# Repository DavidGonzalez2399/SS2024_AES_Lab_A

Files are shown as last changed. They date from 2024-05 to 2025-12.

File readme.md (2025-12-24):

# 🦾 IoT-Based Robotic Arm Sorting System

https://github.com/user-attachments/assets/bf0d83b5-6522-493c-a97c-d7caf1e9e134

## 📘 Project Overview

This repository contains the implementation of an **IoT-based automated sorting system** developed as part of the **Advanced Embedded Systems Lab** for the **Electronic Engineering program**.

The project was developed collaboratively by **Team A** and demonstrates how **distributed embedded systems** communicate wirelessly to control a **robotic arm and conveyor belt** for **color-based object sorting** in an industrial-like scenario.

---

## 🎓 Course Context

- **Course:** Advanced Embedded Systems Lab  
- **Program:** Electronic Engineering  
- **Term:** Summer Term 2024  
- **Project Type:** University Team Project  

---

## 👥 Team Members

- Andrew Antwan  
- **David Gonzalez**  
- Shahzaib Waseem  

---

## 🎯 Target Application

The goal of this project is to simulate an **automated industrial sorting system** for small colored cubes.

The cubes are transported on a conveyor belt. When a cube reaches a predefined position, it is detected by a distance sensor. A robotic arm then picks up the cube, analyzes its color using a color sensor, and decides whether to sort it into a container or return it to the conveyor belt.

This project helps students understand:
- Autonomous embedded systems
- Wireless sensor networks
- MQTT-based communication
- Industrial automation concepts

---

## 🧠 System Architecture

### Main Components

The system is composed of four distributed components:

- Conveyor Belt  
- Distance Sensor (Ultrasonic)  
- Robotic Arm  
- Color Sensor  

Each component runs on its own embedded controller and communicates wirelessly using **MQTT over Wi-Fi**.

---

## 🔌 Hardware & Technologies

### Microcontrollers & Devices

| Device | Responsibility |
|---|---|
| Arduino Uno WiFi Rev2 | Distance sensor & conveyor belt control |
| Raspberry Pi Pico W | Robotic arm motors & color sensor |
| Raspberry Pi 4 | MQTT broker (central hub) |

### Communication

- **Protocol:** MQTT  
- **Broker:** Mosquitto (running on Raspberry Pi 4)  
- **Architecture:** Publish / Subscribe  

---

## 📡 MQTT Communication Model

### Publishers
- Distance Sensor → publishes object detection events  
- Color Sensor → publishes detected color  

### Subscribers
- Conveyor Belt → subscribes to stop/start commands  
- Robotic Arm → subscribes to detection and color messages  

The **robotic arm acts as both a subscriber and a publisher**, making it the central decision-making unit in the system.

---

## 🔄 System Control Flow (One Full Cycle)

The system operates in a continuous loop. One complete cycle is described below:

1. Conveyor belt runs continuously  
2. Distance sensor detects an object  
3. Distance sensor publishes a stop message  
4. Conveyor belt stops  
5. Robotic arm picks up the object  
6. Robotic arm moves the object to the color sensor  
7. Color sensor measures RGB values  
8. Detected color is published via MQTT  
9. Robotic arm decides:
   - If the object is **blue**, it is placed into the sorting container  
   - If the object is **not blue**, it is returned to the conveyor belt  
10. Robotic arm returns to its neutral position  
11. Conveyor belt resumes movement  
12. The cycle repeats  

---

## 🧩 Software Design Overview

### Distance Sensor Module
- Based on the HC-SR04 ultrasonic sensor  
- Detects objects within a configurable distance threshold  
- Publishes detection events via MQTT  

### Color Sensor Module
- Measures RGB values using frequency-based output  
- Determines dominant color via comparison logic  
- Publishes color result via MQTT  

### Motor Control Module
- Converts angles into PWM duty cycles  
- Controls robotic arm positions:
  - Pickup position  
  - Hover above color sensor  
  - Drop position  
  - Reset position  

### Conveyor Belt Module
- Controls stepper motor movement  
- Starts and stops based on MQTT messages  
- Uses direction and step pins for control  

---

## 🧪 Use Cases

### ✅ Blue Object Sorting
- Object is detected  
- Robotic arm picks it up  
- Color sensor detects blue  
- Object is placed into the sorting container  

### 🔁 Non-Blue Object Handling
- Object is detected  
- Robotic arm picks it up  
- Color sensor detects non-blue  
- Object is returned to the conveyor belt  

---

## 🛠️ System Setup & Usage

1. Place a container for blue objects at approximately 60–80° counterclockwise from the robotic arm  
2. Activate a suitable WLAN  
3. Configure SSID and password on all devices  
4. Connect the Raspberry Pi 4 (MQTT broker) to the WLAN  
5. Set the broker IP address on all sensor and actuator nodes  
6. Power all system components  
7. Place a cube on the conveyor belt  
8. Observe automatic detection, classification, and sorting  
9. The system continues operating autonomously  

---

## 📊 Diagrams (Placeholders)

Add the following diagrams to the repository for clarity:

- **Figure 1:** Sequence Diagram  
- **Figure 2:** Block Diagram  
- **Figure 3:** MQTT Communication Layout  
- **Figure 4:** Class Diagram  

---

## 📁 Project Management

- **Version Control:** GitHub  
- **Collaboration Method:**  
  - Weekly virtual planning meetings  
  - In-person hardware integration sessions  
- **Task Assignment:** Volunteer-based and skill-oriented  

---

## 📚 References

- Arduino WiFiNINA Library  
- ArduinoMqttClient Library  
- Mosquitto MQTT Broker  
- Raspberry Pi Pico W (MicroPython)  

---

## ✅ Learning Outcomes

This project demonstrates:
- Distributed embedded system design  
- MQTT-based IoT communication  
- Wireless sensor networks  
- Event-driven control logic  
- Hardware–software co-design  

---

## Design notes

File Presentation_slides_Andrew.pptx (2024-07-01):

## Color Sensor

- makeConnection
- Publish
- Pins
- measureRed
- measureGreen
- measureBlue
- Decide_color

https://www.mouser.com/catalog/specsheets/tcs3200-e11.pdf

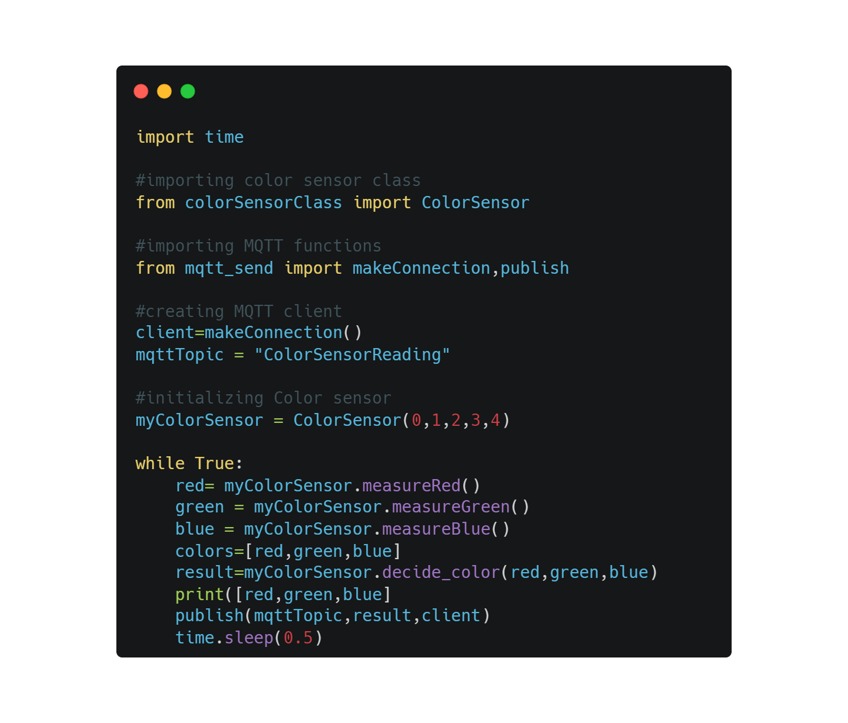
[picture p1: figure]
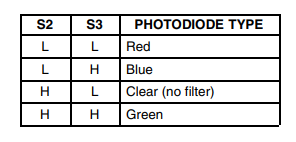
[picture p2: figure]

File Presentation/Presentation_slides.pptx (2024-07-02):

## Robotic Arm

Using MQTT

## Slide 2

Daivd

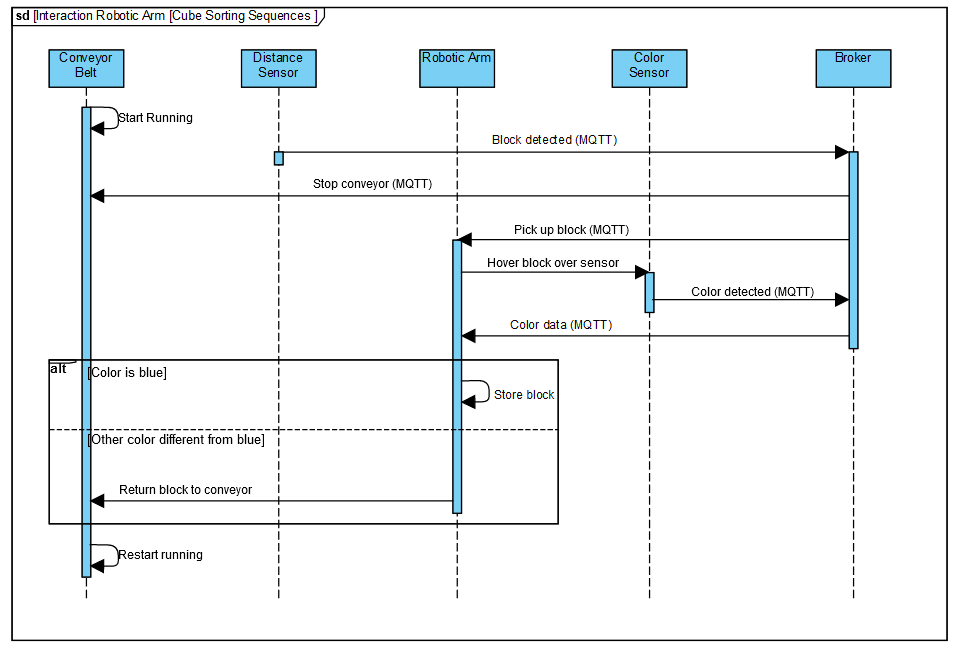
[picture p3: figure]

## Color Sensor

- makeConnection
- Publish
- Pins
- measureRed
- measureGreen
- measureBlue
- Decide_color

Andrew


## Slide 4

Importing libraries for MQTT, BLYNK, time and motor usage

-Declaring global for color sensor readings and message from conveyor belt
-Callbacks from for color sensor and conveyor belt topic and message

-Making connection to the MQTT
-Defining motors angles and speed
-Subscribing to conveyor belt

loop

-When conveyor belt sends a message, the robotic arm goes to conveyor belt and picks the cube
- The robotic arm place the cube on top of the color sensor

When the cube is blue, the robotic arm sorts it in the box, otherwise it goes to the conveyor belt again

David

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
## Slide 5

-Importing libraries for MQTT and WLAN
-Defining the pins for the motor driver, WLAN and MQTT status

-Connecting to WiFi and MQTT broker
-Subscribing to BoxDetection

loop

-if the MQTT is not connected yet, LED for MQTT status is low and the conveyor belt is static

-When no message from the ultrasonic is received, the conveyor belt moves, otherwise it will remain stop until the ultrasonic allows it

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
## Class diagrams

Shahzaib

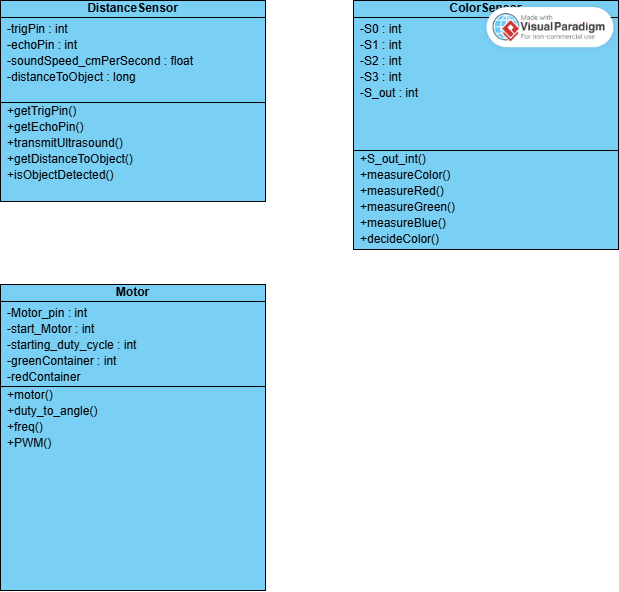
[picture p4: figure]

Conveyer belt

-dirPin : int
-stepPin : int

+move : void
+stop : void

## Conveyor belt motor

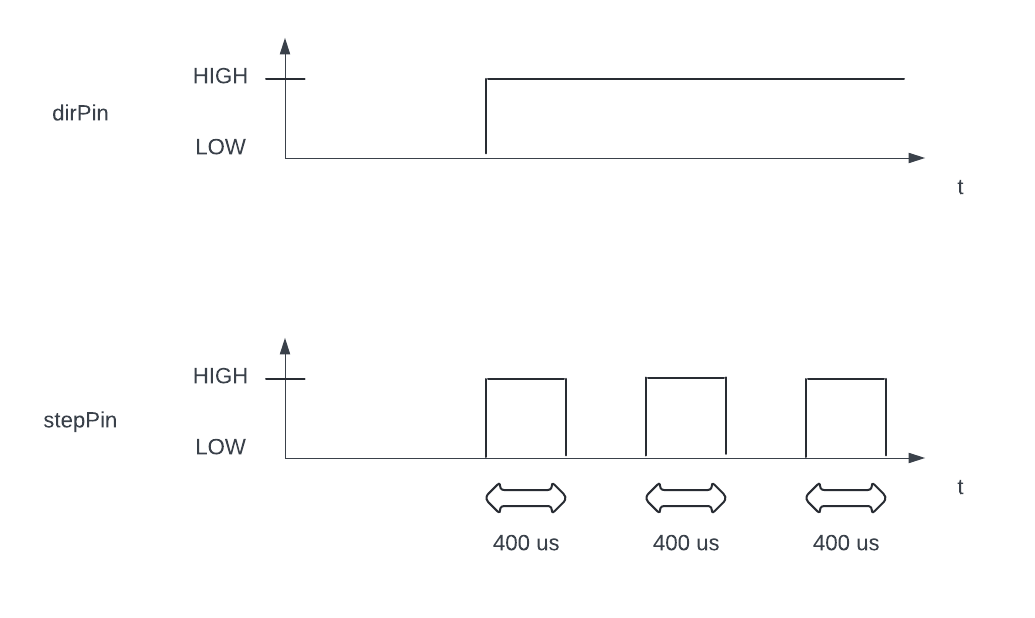
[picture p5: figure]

## Distance sensor (HC-SR04)

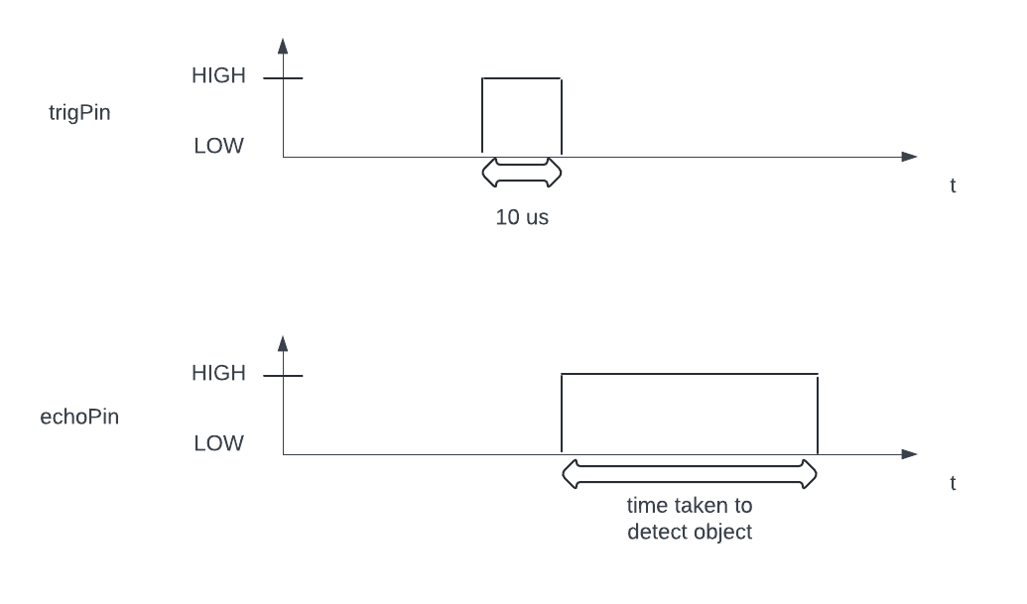
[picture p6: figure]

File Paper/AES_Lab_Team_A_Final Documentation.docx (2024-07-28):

Documentation

Team A

28.05.2024

Important Notes:

- The descriptions in italics in this document (except for some section headings) are exemplary and explanatory and must be removed from the completed report.
- Identify which section of this report was created by which team member
- Your documentation should have ca. 8 pages.

# 1 Team members

Andrew Antwan

David Gonzalez

Shahzaib Waseem

# 2 Introduction

## 2.1 Internet of Things

The internet of things (IoT) consist to connect everyday objects to the internet, which can collect and share the data by utilizing the environment in which they are working. Our project implements devices such as Arduino and Raspberry Pi to control a conveyor belt and robotic arm. These devices talk to each other through the internet to make the system work autonomously.

## 2.2 Wireless Sensor Networks

Wireless sensor networks are collections of small sensors that can sense and transmit data wirelessly, such as temperature or object detection. The color sensor and ultrasonic sensor are a part of this network in our project. They transmit data wirelessly (via an Arduino and a Raspberry Pi) to the main controllers. This facilitates wireless monitoring and control of the robotic arm and conveyor belt.

## 2.3 What is the target application of your project?

Our research aims to implement an automated system for sorting small colored cubes in an industrial environment. The cubes are moved by the conveyor belt; when a cube is detected by the ultrasonic sensor, the robotic arm sorts the cube according to its color. This system can help students to understand how industries sort items quickly and efficiently without needing human intervention.

# 3 Concept description


Figure 1 Sequence diagram

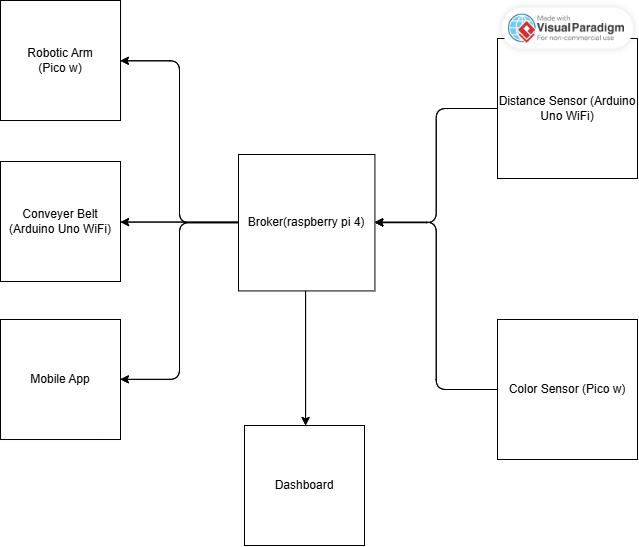
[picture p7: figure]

Figure 2 Block Diagram

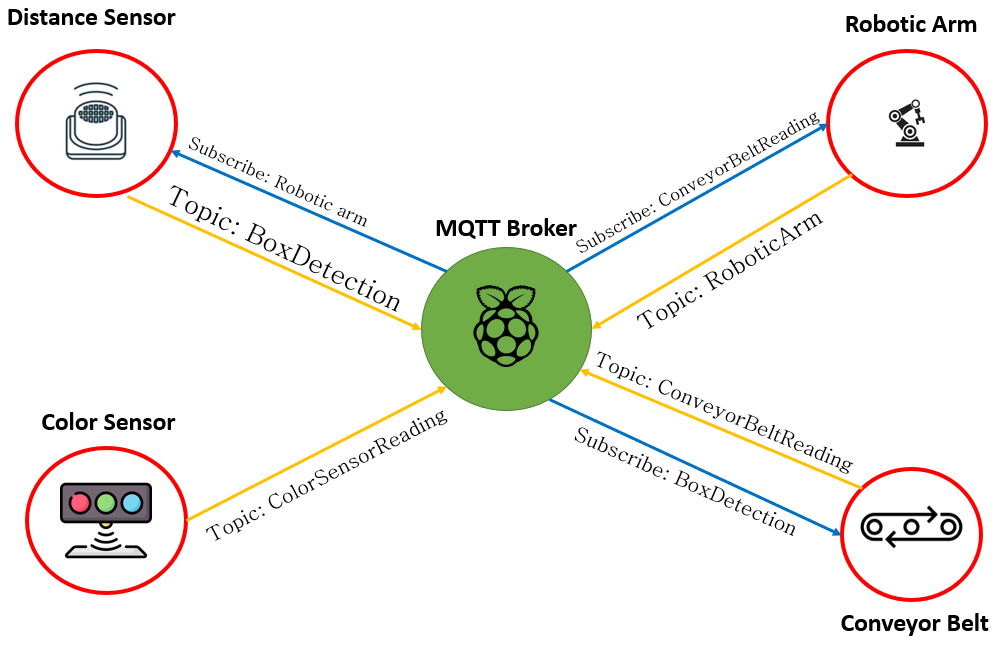
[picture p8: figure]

Figure 3 MQTT Communication layout

The project is mainly consisting of 4 components, namely a Color sensor, Robotic Arm, distance sensor and a conveyer belt. The operation starts by the conveyer belt where it runs until the distance sensor detects that a block has reached a specific region. The distance sensor sends a signal to both the conveyer belt in order to stop and to the robotic arm to pick up the block. The robotic arm picks up the block and hovers it over the color sensor where it sends the color detected to the robotic arm where it decides if the color is to be stored in a separate box or returned to the conveyer belt one more time.

# 4 Project/Team management

## 4.1 Project Methods

We used mainly GitHub as a common repository for file sharing and to sync up all our work. This allowed us to modify each others work if needed without worrying about overwriting the previous work.

## 4.2 Breakdown

For organizing the work we mainly met 2 times a week. One during the weekends -mainly virtually – to organize tasks and divvy up the work amongst ourselves. This was followed by another meeting in person every Tuesday where we show up the progress on the real hardware and where we would brainstorm ideas if anyone is having problems with their tasks.

We didn’t have a rigid hierarchy in the project, the assignment of tasks is mainly done on a volunteer basis depending on the ability and the vision of each.

## 4.3 Division of tasks

Andrew | David | Shahzaib
Color sensor code | Robotic arm code | Distance sensor code
Python MQTT library | Conveyer belt code | Conveyer belt code
Color sensor base 3d design | Robotic Arm 3d design | Arduino MQTT library
Class diagram | Distance sensor 3d design
| Sequence diagram

# 5 Technologies

## Arduino Uno Wifi Rev2

The Arduino Uno Wifi Rev2 is used as a constrained device to control both the distance sensor and the conveyer belt. It offers 48 KB of flash memory with 6.144 KB of SRAM, making it a C0 constrained device. It uses the WiFiNINA library to use the Wi-Fi functionality and the ArduinoMqttClient in order to use mqtt functionality.

## Raspberry Pi Pico W

The raspberry pi pico w is used to control the color sensor and the robotic arm motors. Both of them communicate over wifi with MQTT protocol using the umqtt simple.py library. It offers stronger specs than the pre-mentioned Arduino uno wifi with 264KB of SRAM and 2MB of flash memory which offers more flexibility which is handy specially that it uses Python which compared to C++ used in Arduino programming can require larger storage space.

## Raspberry PI 4

The raspberry pi 4 operates as the central hub that hosts the MQTT broker, sending and receiving all the information from the external nodes

## Mosquitto

The nodes all communicate together using the MQTT protocol where nodes as distance sensor and color sensor are publishers of information and nodes as conveyer belt and robotic arm are subscribers. Keeping in mind that some nodes as the robotic arm is both a subscriber and a receiver at the same time. To use the mqtt protocol we are using the Mosquitto client on the raspberry pi 4 which offers easy setup and reliable performance.

# 6 Implementation

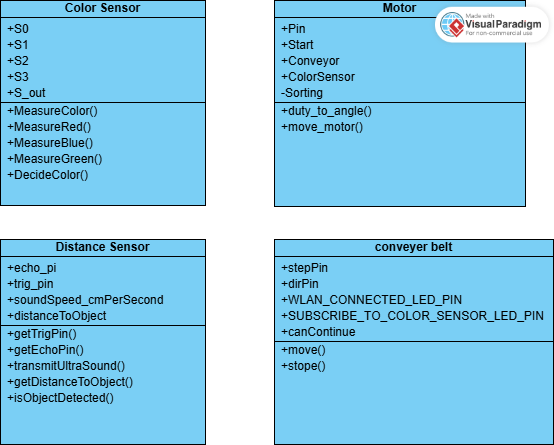
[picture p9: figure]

Figure 3 Class diagram

## Color Sensor

The color sensor has 4 inputs in order they are S0,S1,S2,S3 and one output that gives a frequency inversely relating to the intensity of the color measured. These can be split into two groups: frequency amplification and filter. The pins S0 and S1 are responsible for amplification the measured frequency. In our code these values are set to 1 and 0 respectively to give us a scaling value of 20%. The filter pins S2 and S3 are changed depending on the required color to be measured according to the figure below.

Figure 4 S2 and S3 assignment

These pins are changed using the methods MeasureRed, MeasureGreen and MeasureBlue.

The values received from each function are being compared by the DecideColor function and sees the lowest in the RGB values receives and sets this as the “result” of the measurements.

## Motor

The motor class starts by defining the input pin where the motor is connected and some constants for the various positions the motor will be in. these are the values of the degrees each motor needs to be set to in order to catch the cube from the conveyer belt, hover over the color sensor, store it in the box and return to the start position one more time.

Since the motors need an input of different PWM duty cycles instead of degrees, the function duty_to_angle that transforms the duty cycle to the needed angle. This is then fed into the move_motor function to move to the desired position.

6.3 Distance sensor

The distance sensor class is based on the HCSR-04 proximity or distance sensor and contains two private attributes: the trigger pin and the echo pin. These two attributes are needed in the constructor of the class to instantiate an object of this class. The class uses methods like transmitUltrasound, and getDistanceToObject which although are available for the user to access and use, are mainly components of the isObjectDetected method. This method takes in an argument for an amount of distance in centimeters which serves as a threshold to return true or false when an object is detected within this distance threshold.

6.3 Conveyor belt

The conveyor belt class have three attributes: dirPin, stepPin, and canContinue. The two pins are used in the move and stop methods. Setting dirPin to 1, and generating a 50% duty cycle PWM on the stepPin with a frequency of 1250 Hz or period of 800 microseconds will move the conveyor belt, and setting both these pins to 0 indefinitely will stop the conveyor belt. Upon receiving a message from the distance sensor, depending on the contents of said message, the canContinue property can set to 0 or 1.

# 7 Use Case

The functionality of the system makes it so that there are two possible use cases:

- To let a blue box be sorted out
- To let a non-blue box continue its journey on the conveyor belt

To use our system, the following steps must be taken:

1. Place a container for sorted blue boxes at about 60 to 80 degrees counterclockwise from the robotic arm
2. Activate or turn on a suitable WLAN
3. Ensure that the SSID and password of the WLAN are correctly set up in all the WSNs
4. Connect the Raspberry Pi Broker to the WLAN
5. After the Raspberry Pi Broker connects to the WLAN, ensure that its IP address is correctly set up in all WSNs
6. Provide power to each of the WSNs (robotic arm, color sensor, distance sensor, conveyor belt), and ensure they all connect to the same WLAN and establish an MQTT connection with the Raspberry Pi Broker on its dedicated IP address
7. Place a blue or non-blue box on the conveyor belt, depending on the use case chosen
8. With the conveyor belt powered on, allow the box to travel forward on the conveyor belt
9. Wait for the selected box to get detected by the distance sensor, which would cause the conveyor belt to stop moving
10. Wait for the robotic arm to pick up the box from the conveyor belt at the box’s stopping position
11. Wait for the robotic arm to carry this picked up box towards the color sensor, and allow its color to be determined
12. Depending on the use case chosen, wait for a non-blue box to be placed back on the conveyor belt and have it continue its movement, or wait for a blue box to be dropped off into a container
13. Allow the robotic arm to return to its neutral/starting position. Then repeat from step 7

# 8 Sources/References

Provide the sources on the technologies and algorithms you used in your project (Github).

Advanced Embedded Systems Lab Summer term 2024

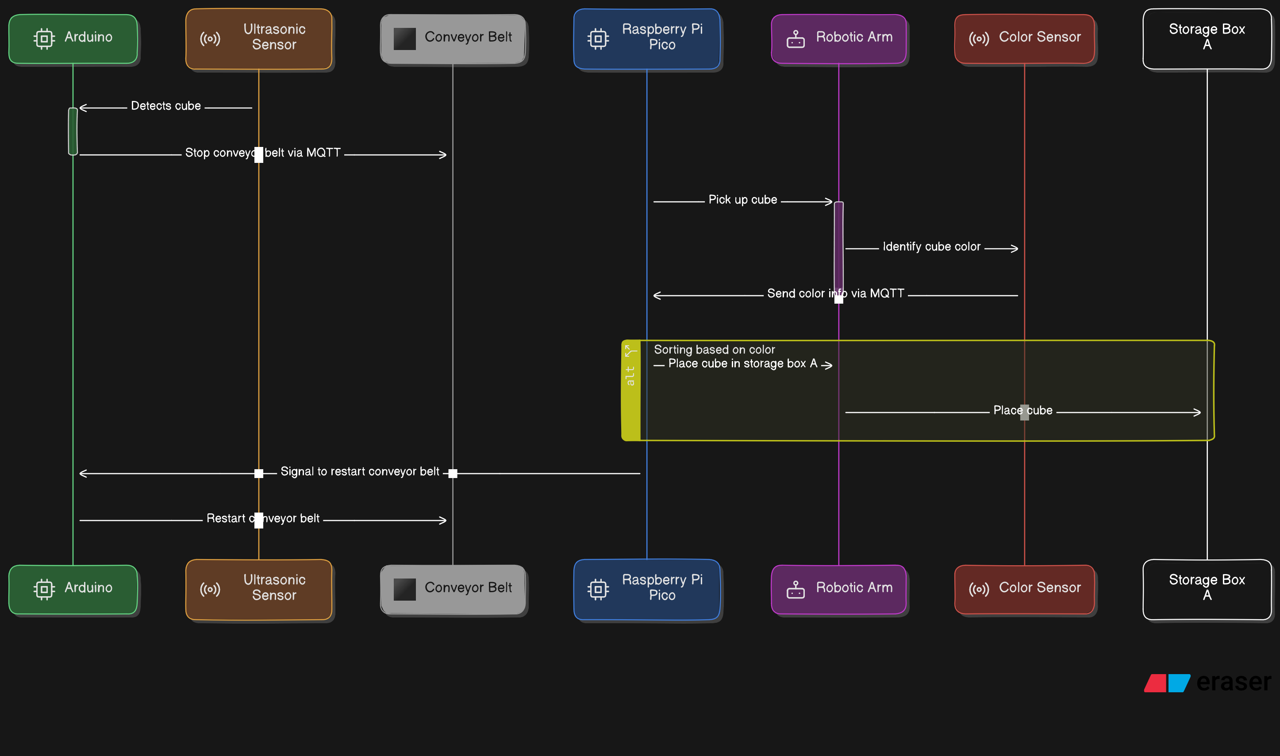
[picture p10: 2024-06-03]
Diagrams/diagram-export-6-3-2024-5_08_39-PM.png

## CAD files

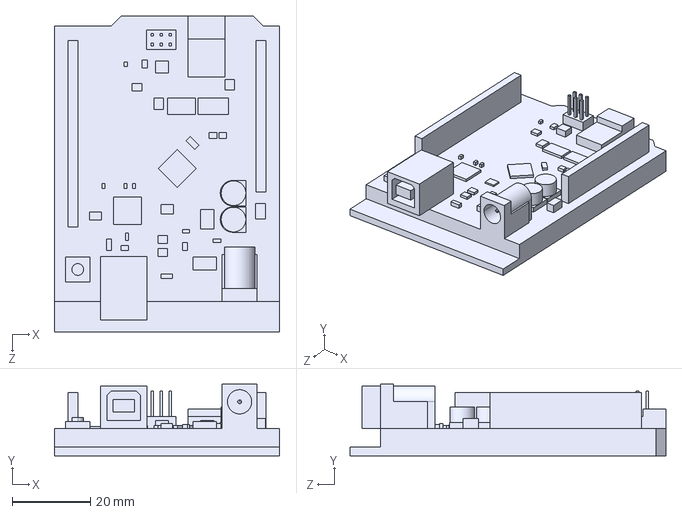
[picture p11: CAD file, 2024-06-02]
Design/arduino-UNO.STEP
57.5 x 18.3 x 80.7 mm

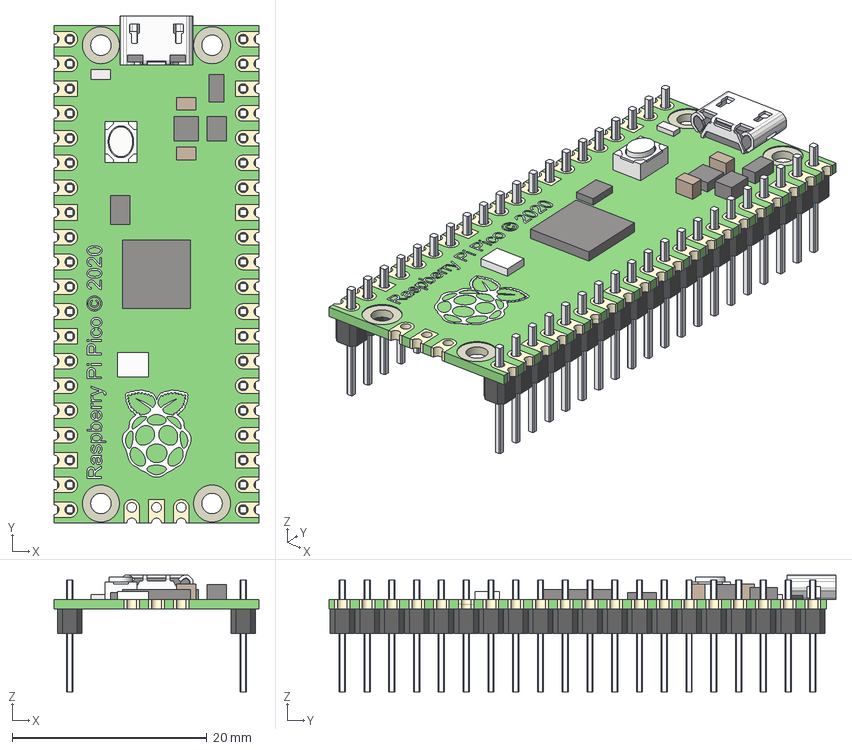
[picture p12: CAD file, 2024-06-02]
Design/raspberry pi pico with contacts.step
21.0 x 52.0 x 12.0 mm
ножка x 20
ножка v3(Mirror) x 20

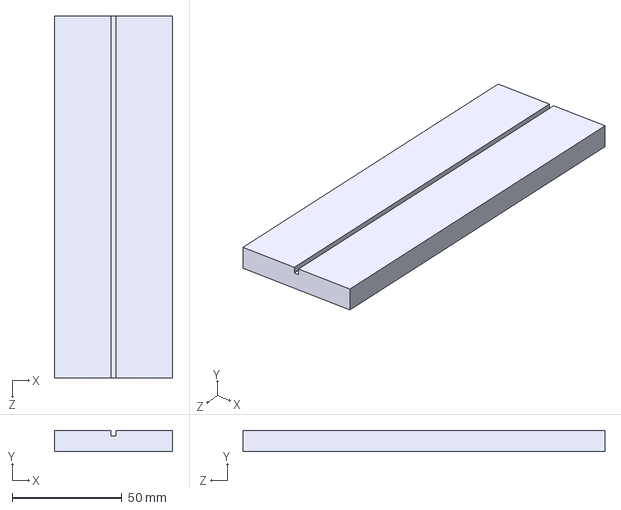
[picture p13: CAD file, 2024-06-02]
Design/breadboard.STEP
54.0 x 9.60 x 165.0 mm

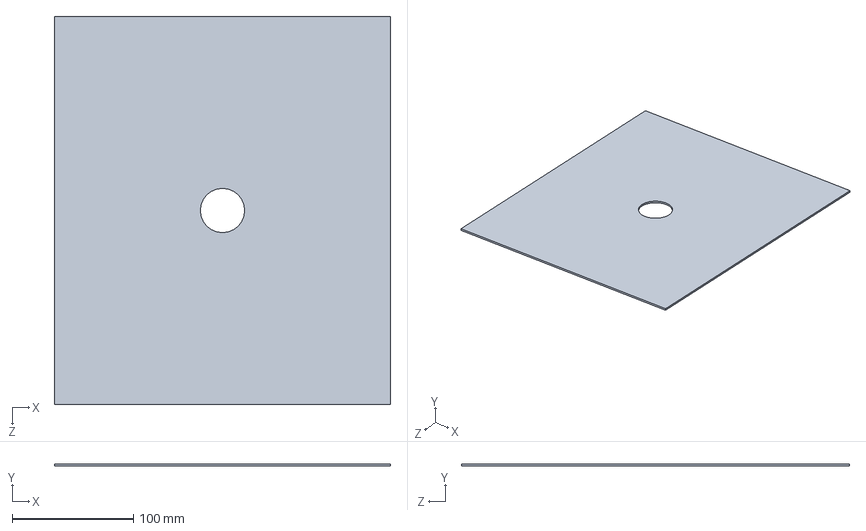
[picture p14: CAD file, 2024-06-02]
Design/Top.SLDPRT
277.3 x 2.00 x 320.0 mm

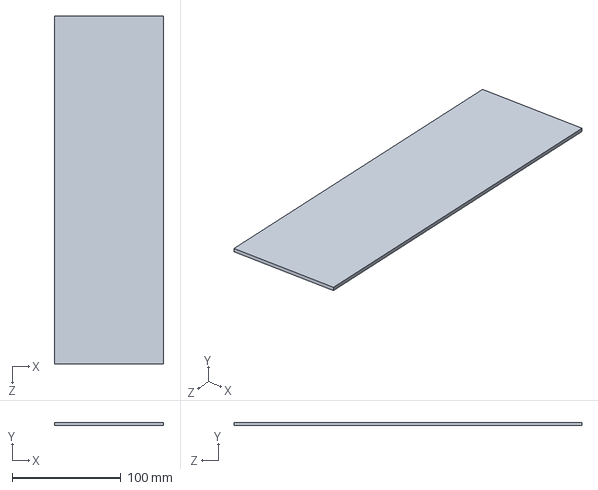
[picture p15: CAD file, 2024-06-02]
Design/Sides.SLDPRT
100.0 x 3.00 x 320.0 mm

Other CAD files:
Design/base.SLDPRT

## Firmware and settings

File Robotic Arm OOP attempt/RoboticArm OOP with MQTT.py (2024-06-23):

from motor_class import Motor, most_common
from mqtt_receive import makeConnection,subscribe
from mqtt_send import publish
import time

readings=[]
conveyerBelt_message=0

def colorSensor_callback(topic, response):
    global readings
    readings.append(response)
    return response
def conveyerbelt_callback(topic,response):
    global conveyerBelt_message
    
    if response==b'1':
        conveyerBelt_message=1
    print(f'response is {response} flag is {conveyerBelt_message}')

client = makeConnection()

motor1_wait_ms=20
motor2_wait_ms=50
motor3_wait_ms=20
motor5_wait_ms=10
motor6_wait_ms=1 

motor_wait_list=[motor1_wait_ms,motor2_wait_ms,motor3_wait_ms,motor5_wait_ms,motor6_wait_ms]
motor1 = Motor(15,101,101,101,0,180,101,0)
motor2 = Motor(8,40,12,12,35,30,15,35)
motor3 = Motor(7,150,164,140,183,150,164,150)
motor5 = Motor(5,155,110,120,106,110,105,110)
motor6 = Motor(6,180,60,60,60,180,180,60)

motor_list=[motor1,motor2,motor3,motor5,motor6]
client.set_callback(conveyerbelt_callback)
subscribe('ConveyorBeltReading', client)
while 1:
    
    client.check_msg()
    while conveyerBelt_message==1:
        for i in range(len(motor_list)):
            motor_list[i].move_motor(motor_list[i].start,motor_list[i].conveyor,motor_wait_list[i])
        #motor3.move_motor(motor3.conveyor,motor3.conveyor_adjustment,motor3_wait_ms)
        #motor3.conveyor=motor3.conveyor_adjustment
        for i in range(len(motor_list)):
            motor_list[i].move_motor(motor_list[i].conveyor,motor_list[i].conveyor_adjustment,motor_wait_list[i])

        for i in range(len(motor_list)):
            motor_list[i].move_motor(motor_list[i].conveyor_adjustment,motor_list[i].color,motor_wait_list[i])

        client.set_callback(colorSensor_callback)
        subscribe('ColorSensorReading', client)
        start=time.ticks_ms()
        end=time.ticks_ms()
        while end-start<5000:
           time.sleep(0.5)
           client.check_msg()
           end=time.ticks_ms()
        result = most_common(readings)
        print(result)
        if result == b'blue':
            for i in range(len(motor_list)):
                motor_list[i].move_motor(motor_list[i].color,motor_list[i].storing,motor_wait_list[i])
            for i in range(len(motor_list)):    
                motor_list[i].move_motor(motor_list[i].storing,motor_list[i].start,motor_wait_list[i])
        else:
            for i in range(len(motor_list)):
                motor_list[i].move_motor(motor_list[i].color,motor_list[i].returnbox_adjustment,motor_wait_list[i])
            for i in range(len(motor_list)):
                motor_list[i].move_motor(motor_list[i].returnbox_adjustment,motor_list[i].returnbox,motor_wait_list[i])
            for i in range(len(motor_list)):
                motor_list[i].move_motor(motor_list[i].returnbox,motor_list[i].start,motor_wait_list[i])
        readings=[]
        publish('RoboticArm','1',client)
        client.set_callback(conveyerbelt_callback)
        subscribe('ConveyorBeltReading', client)
        conveyerBelt_message=0

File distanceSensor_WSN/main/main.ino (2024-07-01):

#include "DistanceSensor.h"
#include "WLAN.h"
#include "MQTT.h"

#define TRIG_PIN 12
#define ECHO_PIN 11
#define WLAN_CONNECTED_LED_PIN 7
#define PUBLISH_TO_CONVEYER_BELT_LED_PIN 6
#define SUBSCRIBE_TO_COLOR_SENSOR_LED_PIN 5
#define NEAR_THRESHOLD_CMS 18

DistanceSensor distanceSensor(TRIG_PIN, ECHO_PIN);

void setup() {
  
  Serial.begin(9600);
  while (!Serial) {
    ; // wait for serial port to connect. Needed for native USB port only
  }
  pinMode(LED_BUILTIN, OUTPUT);
  pinMode(WLAN_CONNECTED_LED_PIN, OUTPUT);
  pinMode(PUBLISH_TO_CONVEYER_BELT_LED_PIN, OUTPUT);
  pinMode(SUBSCRIBE_TO_COLOR_SENSOR_LED_PIN, OUTPUT);
  
  connectToWifi();

  connectToMQTTBroker();

  digitalWrite(LED_BUILTIN, HIGH);

  subscribeToTopic("RoboticArm");

}


void loop() {

  if(!mqttClient.connected()){

    digitalWrite(LED_BUILTIN, LOW);

    connectToWifi();

    connectToMQTTBroker();

  } else {

    digitalWrite(LED_BUILTIN, HIGH);
  
    if(distanceSensor.isObjectDetected(NEAR_THRESHOLD_CMS)){

      publishMessage("1", "BoxDetection");
      
    }

    mqttClient.poll();

  }

  delay(100); 

}

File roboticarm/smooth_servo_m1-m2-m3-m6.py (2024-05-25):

import machine
import time

# Define pin numbers for each motor
MOTOR1_PIN = 15
MOTOR2_PIN = 8
MOTOR3_PIN = 7
MOTOR4_PIN = 6

START_motor1 = 50
START_motor2 = 40
START_motor3 = 120
START_motor4 = 180

RED_CONTAINER_motor1 = 135
RED_CONTAINER_motor2 = 30


GREEN_CONTAINER_motor1 = 160
GREEN_CONTAINER_motor2 = 10
GREEN_CONTAINER_motor3 = 140
GREEN_CONTAINER_motor4 = 70


# Initialize PWM objects for each motor
MOTOR1 = machine.PWM(machine.Pin(MOTOR1_PIN))
MOTOR2 = machine.PWM(machine.Pin(MOTOR2_PIN))
MOTOR3 = machine.PWM(machine.Pin(MOTOR3_PIN))
MOTOR4 = machine.PWM(machine.Pin(MOTOR4_PIN))

MOTOR1.freq(50)  # Set PWM frequency for all motors
MOTOR2.freq(50)  # Set PWM frequency for all motors
MOTOR3.freq(50)  # Set PWM frequency for all motors
MOTOR4.freq(50)  # Set PWM frequency for all motors

#motor1
current_duty1 = 0
starting_duty_cycle=int(6553 / 180 * START_motor1 + 1638)

def duty_to_angle(angle, which_motor):
    global current_duty1, starting_duty_cycle, current_duty2, starting_duty_cycle2
    
    duty_cycle = int(6553 / 180 * angle + 1638)
    
    if which_motor == 1:  
        # Motor 1 movement
        if duty_cycle > current_duty1: 
            for i in range(starting_duty_cycle, duty_cycle, 1):
                MOTOR1.duty_u16(i)
                time.sleep_ms(1)
            current_duty1 = duty_cycle
        elif duty_cycle < current_duty1:
            for i in range(current_duty1, duty_cycle, -1):
                MOTOR1.duty_u16(i)
                time.sleep_ms(1)
            current_duty1 = duty_cycle
    
    elif which_motor == 2:
        # Motor 2 movement
        MOTOR2.duty_u16(duty_cycle)
    elif which_motor == 3:
        # Motor 3 movement
        MOTOR3.duty_u16(duty_cycle)
    elif which_motor == 4:
        # Motor 3 movement
        MOTOR4.duty_u16(duty_cycle)


def motor1(angle):
    duty_to_angle(angle, 1)
    
def motor2(origin,destiny):
    # Move MOTOR2 forward from 40 to 0 degrees
    if origin > destiny:
        for i in range(origin, destiny, -1):
            duty_to_angle(i, 2)
            time.sleep(0.09)
    elif destiny > origin:
        for i in range(origin, destiny, 1):
            duty_to_angle(i, 2)
            time.sleep(0.09)
def motor3(origin,destiny):
    # Move MOTOR3 forward from 120 to 180 degrees
    if origin < destiny:
        for i in range(origin, destiny, 1):
            duty_to_angle(i, 3)
            time.sleep_ms(20)
    elif destiny < origin:
        for i in range(origin, destiny, -1):
            duty_to_angle(i, 3)
            time.sleep_ms(20)
def motor4(destiny):
    # Move MOTOR4 forward from 180 to 100 degrees
    duty_to_angle(destiny, 4)
    time.sleep(1)
    

# Test your motor control functions
motor1(START_motor1)
motor1(GREEN_CONTAINER_motor1)
motor2(START_motor2,GREEN_CONTAINER_motor2)
motor3(START_motor3,GREEN_CONTAINER_motor3)
motor4(GREEN_CONTAINER_motor4)
motor1(START_motor1)
motor4(START_motor4)
motor3(GREEN_CONTAINER_motor3,START_motor3)
motor2(GREEN_CONTAINER_motor2,START_motor2)

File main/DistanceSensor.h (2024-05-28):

#ifndef DistanceSensor_h
#define DistanceSensor_h
#include "Arduino.h" 


class DistanceSensor {

private:

  int _trigPin;
  int _echoPin;
  float _soundSpeed_cmPerSecond = 0.0343;
  long _distanceToObject;


public:

  DistanceSensor(int trigPin, int echoPin){
    
    _trigPin = trigPin;
    _echoPin = echoPin;
    _soundSpeed_cmPerSecond = 0.0343;

    pinMode(trigPin, OUTPUT);
    pinMode(echoPin, INPUT);

  };

  int getTrigPin(){

    return _trigPin;

  };

  int getEchoPin(){

    return _echoPin;

  };

  void transmitUltrasound(){

    digitalWrite(_trigPin, LOW);
    delayMicroseconds(5);
    digitalWrite(_trigPin, HIGH);
    delayMicroseconds(10);
    digitalWrite(_trigPin, LOW);

  }

  long getDistanceToObject(){

    transmitUltrasound();

    return (pulseIn(_echoPin, HIGH)/2) / 29.1;

  }

  bool isObjectDetected(float thresholdDistance){

    return getDistanceToObject() < thresholdDistance;

  }
  

};

#endif

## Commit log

2024-05-14 Add files via upload
    motor 2 is not working properly, even though I placed starting_duty_cycle2 in the for loop, it totally ignore what I coded
    [smooth_servo_m1andm2.py]
2024-05-25 Add files via upload
    The robotic arm moves to certain directions that are specified in the first lines.
    What is next:
    -Arrange code
    -Integrate the robotic arm code with the other parts of the project by using MQTT
2024-05-26 updated color sensor code in OOP
2024-05-28 arduino mqtt
2024-05-28 Create main.ino
    basic code for the conveyor belt
2024-05-29 cleaned color sensor code, robotic arm oop attempt
    Added comments for color sensor and organized Pi MQTT code.
    Attempted to organize Robotic arm into OOP design. code runs but further tests are needed
2024-06-02 overall design
    first draft for housing of the robotic arm and other components.
    [Sides.SLDPRT, Top.SLDPRT, arduino-UNO.STEP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]
2024-06-06 Conveyor belt client
    now the conveyor belt can communicate with the broker. The conveyor belt moves by default, until it receives a 0 from the broker, when it gets 1 then it restarts
    [MQTT.h, main.ino]
2024-06-23 Create RoboticArm OOP with MQTT.py
    This code is the most optimal one
    3 new arguments has been added to the new motorclass
    the robotic arm sends a 1 when the operation is ready
    additionally, the robotic arm performs faster and has more adjustments to avoid collisions
    [RoboticArm OOP with MQTT.py]
2024-06-23 Update main.ino
    now the conveyor belt connects to the MQTT and sends 1 to the robotic arm when the operations stops
2024-06-23 Update MQTT.h
    now we made sure the conveyor belt sends 1 when it stops running
2024-06-29 Removed delays between each distance sensor reading
2024-07-02 Added conveyor belt class diagram
2024-07-02 Added conveyor belt and distance sensor gantt charts
2025-12-24 Revise README for IoT-Based Robotic Arm Project
    Updated project details and team members for the IoT-based robotic arm sorting system.
